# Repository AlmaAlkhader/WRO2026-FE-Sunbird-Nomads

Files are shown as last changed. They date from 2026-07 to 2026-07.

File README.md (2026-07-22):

<h1 align="center">Sunbird Nomads</h1>

<h3 align="center">
WRO 2026 Future Engineers · Palestine 🇵🇸
</h3>

<p align="center">
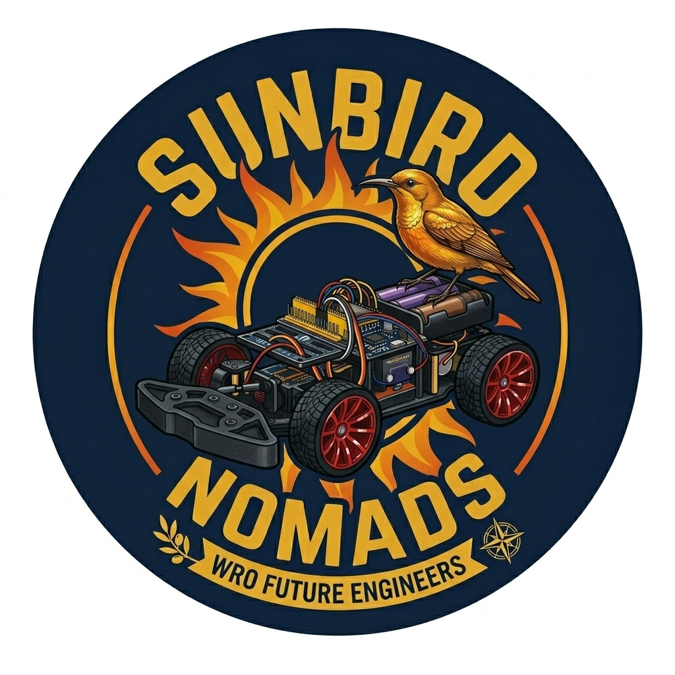
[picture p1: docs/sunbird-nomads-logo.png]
Sunbird Nomads team logo
  
</p>

<p align="center">
An autonomous vehicle engineered through testing, failure, redesign, and continuous improvement.
</p>

---

##  Repository Contents

| Folder | Contents |
|---|---|
| [`t-photos/`](t-photos/) | Official and informal team photos |
| [`v-photos/`](v-photos/) | Vehicle photographs from every required angle |
| [`video/`](video/) | Driving demonstration videos |
| [`schemes/`](schemes/) | Electrical and wiring diagrams |
| [`src/`](src/) | Testing and final robot software |
| [`models/`](models/) | 3D-printing and CAD files |
| [`docs/`](docs/) | Engineering diagrams and detailed investigations |

---
##  Why “Sunbird Nomads”?

<p align="center">
  Visual explanation of the Sunbird Nomads team name
</p>

The **Palestine sunbird** is a small, colourful bird native to our region and recognized as the national bird of Palestine. For Palestinians, it represents our land, identity, freedom, and resilience.

The word **Nomads** reflects our engineering journey constantly exploring, adapting, learning, and moving toward better solutions.

Together, **Sunbird Nomads** represents a Palestinian team deeply rooted in its homeland while continuing to move forward and discover new possibilities.

---
## Our Journey

We are **Alma Alkhader** and **Sara Afifi**, two second-year engineering students at Birzeit University brought together by a shared interest in robotics. This is our second year competing in the WRO Future Engineers category. Our experience began with our [WRO 2025 BiruniVerse project](https://github.com/AlmaAlkhader/WRO2025-BiruniVerse), where we gained our first practical experience designing, building, and programming an autonomous vehicle.

###  Meet the Team

<table>
  <tr>
    <th width="50%">Alma Alkhader</th>
    <th width="50%">Sara Afifi</th>
  </tr>
  <tr>
    <td align="center">
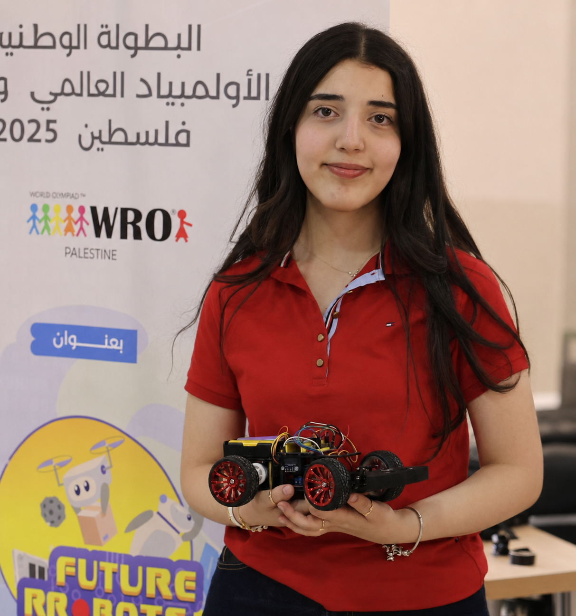
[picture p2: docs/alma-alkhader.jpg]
Alma Alkhader
      
    </td>
    <td align="center">
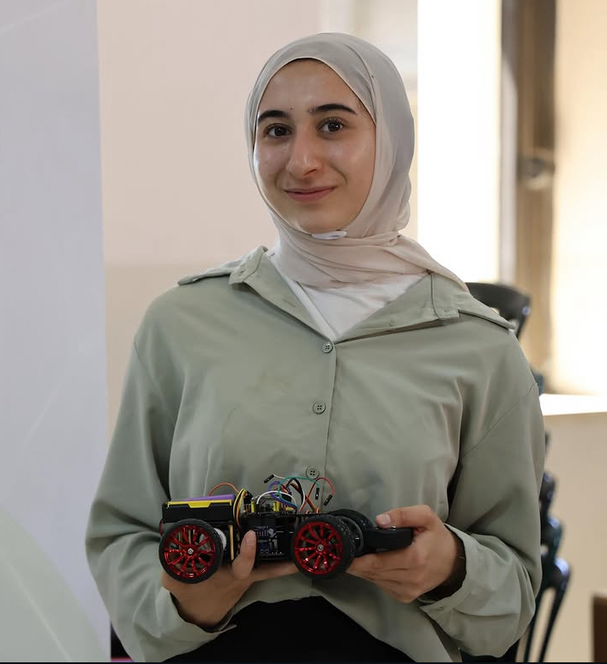
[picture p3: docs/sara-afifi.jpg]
Sara Afifi
      
    </td>
  </tr>
  <tr>
    <td valign="top">
      <strong>Occupation:</strong> Computer Engineering student<br><br>
      <strong>Academic level:</strong> Second year<br><br>
      <strong>Membership:</strong> IEEE Robotics and Automation Society (RAS), Birzeit University Student Branch<br><br>
      <strong>Interest:</strong> Robotics and autonomous systems<br><br>
      <strong>Team responsibilities:</strong> Power system, electronics, wiring, sensor integration, Raspberry Pi setup, and control software
    </td>
    <td valign="top">
      <strong>Occupation:</strong> Mechanical Engineering student<br><br>
      <strong>Academic level:</strong> Second year<br><br>
      <strong>Membership:</strong> Technical member of IMechE at Birzeit University<br><br>
      <strong>Specialization:</strong> Mechanical design and manufacturing<br><br>
      <strong>Team responsibilities:</strong> Chassis development, steering mechanism, component placement, measurements, and custom-designed mounts
    </td>
  </tr>
</table>

Our different specializations allowed us to approach the robot from two connected perspectives. Alma concentrated on making the electronics and software work reliably, while Sara focused on ensuring that the mechanical design could support those systems and move effectively. Nearly every improvement required both sides to work together.

<p align="center">
  Alma's electronics path and Sara's mechanical-design path joining into one robot engineering journey
  <br>
  <em>Two specializations developed together through every prototype, redesign, and milestone.</em>
</p>

Our first robot of the 2026 season came to life on **May 19, 2026**, powered by an ESP32. Although it completed the Open Challenge, it still faced major issues with steering, power delivery, and the rear axle. Over the following weeks, we redesigned and improved these systems while balancing the project with our university exams and coursework.

By the local competition on **July 13, 2026**, the robot had evolved significantly. After moving from the ESP32 to a Raspberry Pi and making several mechanical and electrical improvements, it achieved the maximum score in the Open Challenge. We earned **second place** and qualified for the national competition.

We are proud of how far the robot has come. Every test, mistake, and redesign contributed to the final architecture documented in this repository.

## Design Strategy

Our robot is built on a **4WD Arduino RC car chassis**, which we chose as a reliable starting point that allowed us to focus on developing and improving the robot for the WRO Future Engineers competition.

While the kit provided a solid foundation, it also presented several challenges:

* **Limited space** for mounting electronic components, requiring us to carefully redesign the layout and create custom 3D-printed mounts.
* **Minimal assembly documentation**, which led us to reverse-engineer parts of the chassis and solve several mechanical issues during development.

As the project evolved, we continuously modified the original design to better meet the competition's requirements, improving the mechanical structure, electronics integration, and overall reliability.

# Hardware Design
## Mobility and Mechanical Design

The mechanical system uses a conventional car layout: a **single rear drive axle** provides forward and reverse motion, while an **S3003 servo** steers the two front wheels through linkages. This layout satisfies the WRO requirement for a four-wheeled vehicle with one driving axle and one steering actuator, and it behaves more like a road car than a differential-drive robot.

### Chassis and Drive Layout

Our robot is based on the [**RoboticX 4WD RC Smart Car Chassis with S3003 Servo and Bearing Kit**](https://roboticx.ps/product/4wd-rc-smart-car-chassis-with-s3003-metal-servo-bearing-kit-for-arduino/). 
We selected the kit as a reliable mechanical starting point, but we did not keep its original component layout. Its acrylic plate had limited usable space and mounting holes intended mainly for an Arduino. Our Raspberry Pi, power system, camera, motor controller, and sensors required a new structure, so we designed a custom middle plate and an upper electronics layer.

<p align="center">
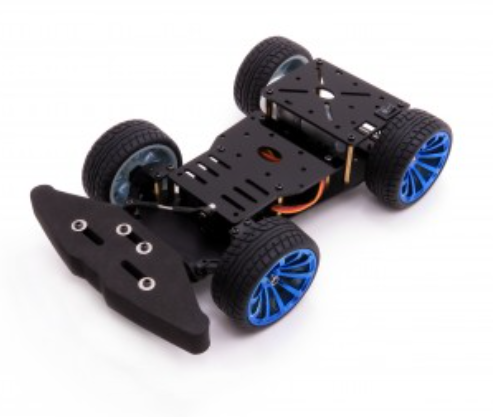
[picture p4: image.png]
Original RoboticX rear-wheel-drive chassis
  
  <br>
  <em>Original chassis before adding the custom two-level electronics structure.</em>
</p>

### Final Vehicle Dimensions

| Dimension | Final value | How it was obtained | Why it matters |
|---|---:|---|---|
| Overall length | 248 mm | Measured vehicle length; also matches the chassis listing | Determines WRO envelope margin and parking-space length |
| Chassis width | 146 mm | Published chassis width | Determines lateral clearance and field-centering geometry |
| Assembled height | 126 mm | Measured with the upper electronics layer installed | Confirms that the two-level design remains inside the height limit |
| Wheelbase | 137 mm | Measured axle-to-axle distance | Used in steering-angle calculations |
| Front track width | 117 mm | Measured between the front wheel centerlines | Used to calculate different inner and outer steering angles |
| Wheel diameter | 64 mm | Published wheel diameter | Determines distance travelled per wheel revolution |
| Ground clearance | 19 mm | Measured from the ground to the lowest chassis surface | Reduces the chance of the plate catching on small field irregularities |

<p align="center">
  Top and side views with the robot's mechanical dimensions and field-fit calculations
  <br>
  <em>Final dimensions, WRO size margins, wheel travel, and parking-space calculations.</em>
</p>

The [WRO 2026 rules](https://wro-association.org/wp-content/uploads/WRO-2026-Future-Engineers-Self-Driving-Cars-General-Rules.pdf) limit the vehicle to **300 × 200 mm** and **300 mm in height**. Comparing the final robot with that envelope gives:

```text
Length margin = 300 − 248 = 52 mm
Width margin  = 200 − 146 = 54 mm
Height margin = 300 − 126 = 174 mm
```

These are total envelope margins. They show that the second electronics layer and sensor mounts remain within the dimensional limit without requiring parts to be removed before inspection.

### Field-Centering and Parking Geometry

During setup, we established the robot's centerline by measuring from the track walls to the midpoint of the vehicle. For a corridor width $W_t$, a centered robot midpoint is:

$$d_{mid}=\frac{W_t}{2}$$

The open challenge may use a **1000 mm** or **600 mm** corridor, while the obstacle challenge uses a **1000 mm** corridor. The nominal midpoint references are therefore:

| Nominal corridor width | Wall-to-midpoint reference | Side clearance with a 146 mm robot |
|---:|---:|---:|
| 1000 mm | 500 mm | $(1000-146)/2=427$ mm per side |
| 600 mm | 300 mm | $(600-146)/2=227$ mm per side |

The WRO rules allow dimensional tolerance in the field, so these values define the geometry rather than a single inflexible sensor threshold.

For the obstacle challenge, the parking space is **200 mm wide**, and its length is $1.5$ times the vehicle length:

```text
Parking length = 1.5 × 248 = 372 mm
Longitudinal allowance = 372 − 248 = 124 mm
Lateral allowance = 200 − 146 = 54 mm
Centered lateral allowance = 54 / 2 = 27 mm per side
```

The remaining **VL53L0X ToF sensor is mounted at the rear** and is used to monitor the final rear clearance during parking. Its job is separate from the left and right ultrasonic sensors used for wall sensing.

### Custom Plate Development

After identifying the required components, we designed custom middle and top plates to increase usable mounting area while preserving access to wiring and controls. The plate design went through **four physical iterations**. Our initial measurements were not accurate enough to produce a correct fit on the first attempt, so every printed version was installed on the real chassis, checked, remeasured, and revised.

<table align="center">
  <tr>
    <td align="center">
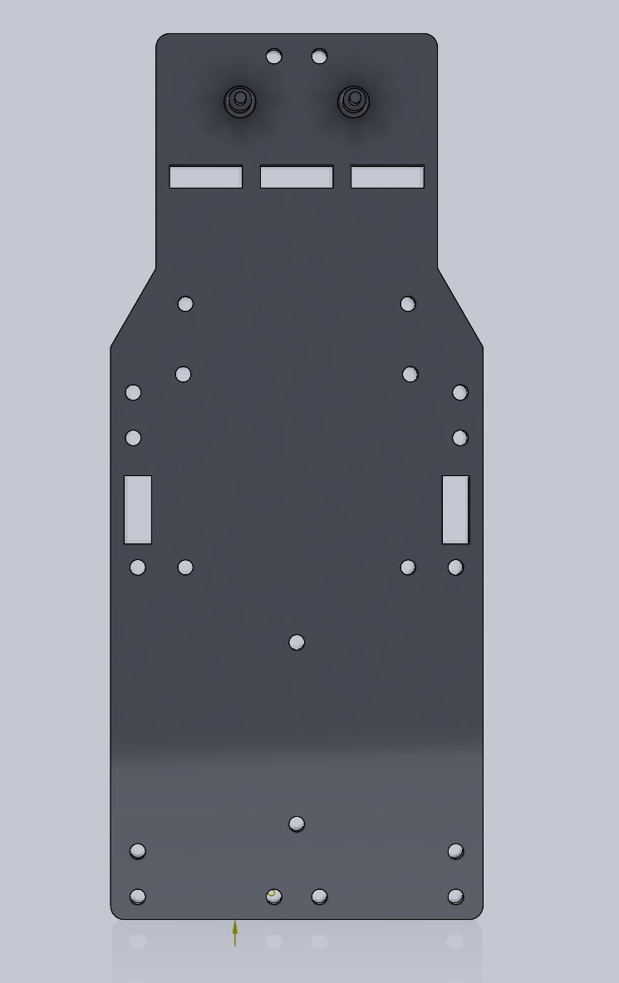
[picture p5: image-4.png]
middle plate
      <br>
      <em>Early prototype</em>
    </td>
    <td align="center">
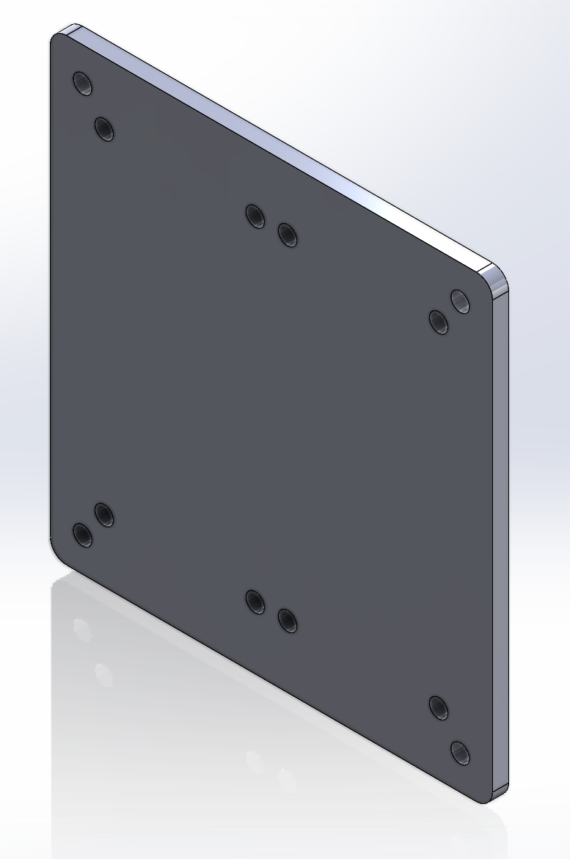
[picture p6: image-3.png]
top plate
      <br>
      <em>Final design</em>
    </td>
  </tr>
</table>

<p align="center">
  Measure, model, print, fit-test, and refine loop used across four plate versions
  <br>
  <em>The physical fit test converted measurement errors into specific CAD corrections.</em>
</p>

The process was not simply “print until it looks right.” Each loop checked whether components fitted without interference, whether cables could reach without being sharply bent, whether switches remained accessible, and whether the camera and sensors had an unobstructed view. Repeating the cycle improved component placement, cable management, and service access.

### 3D-Printing Configuration

The final plates were produced by FDM printing on an **ELEGOO Centauri Carbon** using **Rapid PETG**. ELEGOO lists PETG as a supported material and specifies a **0.1–0.4 mm** layer-height range for this printer; our **0.12 mm** setting is near the fine-detail end of that range.

| Setting | Final value | Engineering purpose |
|---|---:|---|
| Printer | ELEGOO Centauri Carbon | Enclosed CoreXY FDM printer used for the final plates |
| Material | Rapid PETG | Tougher functional material for plates handled and reassembled repeatedly |
| Layer height | 0.12 mm | Finer vertical resolution and more controlled fit, at the cost of longer print time |
| Wall loops | 3 | Adds perimeter stiffness around the plate edges and mounting holes |
| Sparse infill pattern | Gyroid | Distributes internal support in multiple directions without using solid infill everywhere |
| Sparse infill density | 25% | Balances rigidity, material use, mass, and print time |

Compared with the printer's commonly recommended **0.20 mm** layer height, a 0.12 mm layer produces approximately:

$$\frac{0.20}{0.12}=1.67$$

or **67% more layers for the same part height**. We accepted the longer printing time because dimensional fit and clean mount features were more important than minimum production time for the final plates.

Printer reference: [ELEGOO Centauri Carbon specifications](https://eu.elegoo.com/en-be/products/centauri-carbon).

## Steering Calibration

The chassis allows the steering-rod lengths to be adjusted. We used this to approximate **Ackermann steering**, where the inner front wheel turns more sharply than the outer front wheel because the two wheels follow different radii around the same instantaneous center of rotation.

<p align="center">
  Animated Ackermann steering geometry showing inner and outer wheel angles and the instantaneous center of rotation
  <br>
  <em>Animated steering geometry for an illustrative 200 mm turn radius. The 44° inner and 28° outer angles are calculated from our measured wheelbase and front track.</em>
</p>

<p align="center">
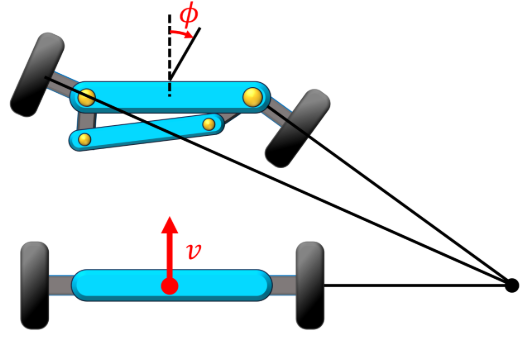
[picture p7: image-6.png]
Ackermann steering mechanism
  
</p>

For low-speed cornering, the centerline steering angle is:

$$\delta=\tan^{-1}\left(\frac{L}{R}\right)$$

Using the measured wheelbase $L=137$ mm and turning radius $R=525$ mm:

$$\delta=\tan^{-1}\left(\frac{137}{525}\right)=14.6^\circ\approx15^\circ$$

The measured front track width $t=117$ mm lets us estimate the ideal inner and outer wheel angles:

$$\delta_{in}=\tan^{-1}\left(\frac{L}{R-t/2}\right)
=\tan^{-1}\left(\frac{137}{525-58.5}\right)=16.4^\circ$$

$$\delta_{out}=\tan^{-1}\left(\frac{L}{R+t/2}\right)
=\tan^{-1}\left(\frac{137}{525+58.5}\right)=13.2^\circ$$

| Steering reference | Calculated angle |
|---|---:|
| Vehicle centerline | 14.6° |
| Inner front wheel | 16.4° |
| Outer front wheel | 13.2° |
| Inner-to-outer difference | 3.2° |

We adjusted the steering rods until the wheels followed this geometry as closely as the kit mechanism allowed. This reduces tire scrub compared with forcing both front wheels to the same angle.

## Mounts

The camera and distance sensors use custom-designed mounts so their position does not change during a run while remaining accessible for maintenance.

### ToF Sensor Mount — Initial Design and Final Rear Use

Our first approach used multiple Time-of-Flight sensors for wall sensing. After several design iterations, we produced a stable ToF mount.

<p align="center">
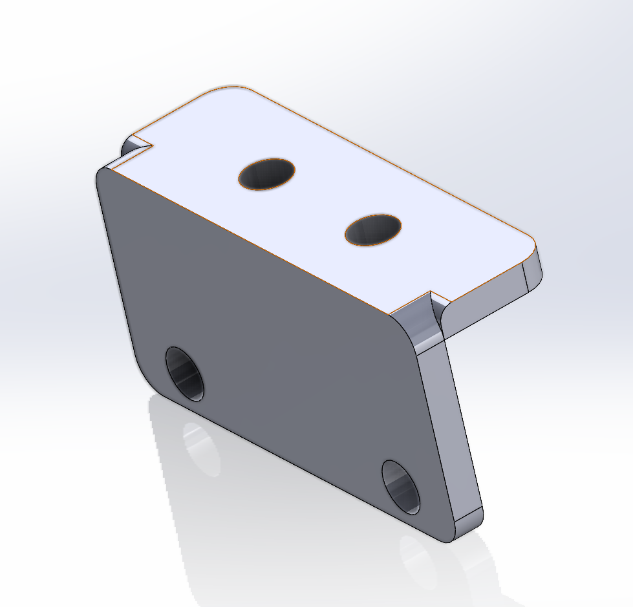
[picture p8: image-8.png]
ToF sensor mount design
  
  <br>
  <em>ToF sensor mount design.</em>
</p>

Testing showed that ToF sensors were not suitable as our main wall sensors on the WRO mat because infrared return varied with dark surfaces and target geometry. We replaced the side-facing ToF plan with ultrasonic wall sensing. **One VL53L0X remains mounted on the back of the vehicle for short-range parking alignment.**

### Ultrasonic Sensor Mount — Final Design

The left and right ultrasonic sensors required a different mount that kept both transducers clear of the chassis.

<p align="center">
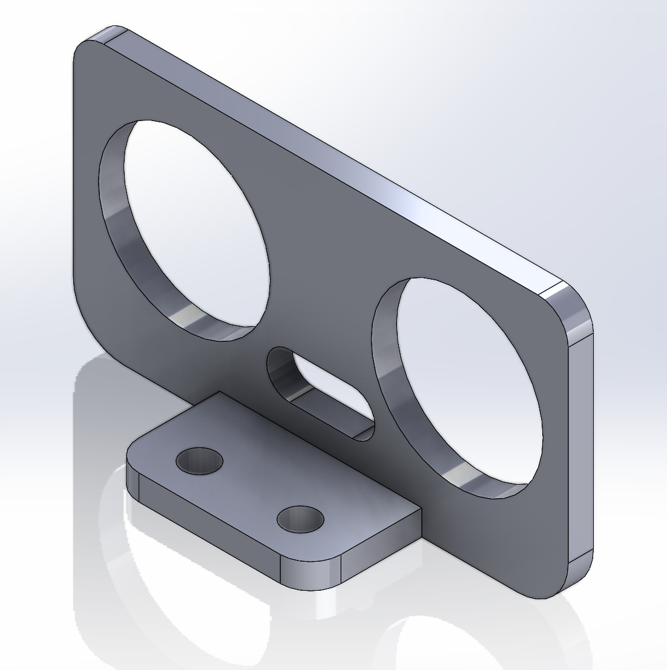
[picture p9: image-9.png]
Ultrasonic sensor mount design
  
  <br>
  <em>Final ultrasonic sensor mount design.</em>
</p>

The mount uses a **friction-fit mechanism** to hold the sensor without screws. This makes installation and replacement fast, but it also made print accuracy important: an undersized opening could damage the board, while an oversized opening allowed the sensor angle to change.

### Pi Camera Mount

The camera requires a stable, repeatable position because a change in height or angle changes the apparent location of the traffic pillars. We designed a screw-mounted holder with an unobstructed lens opening.

<p align="center">
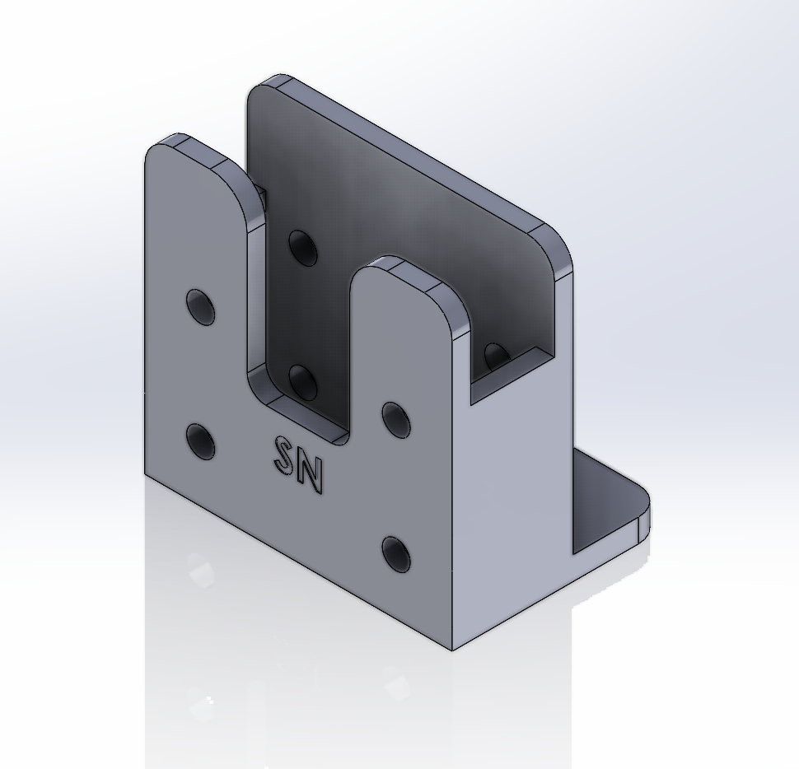
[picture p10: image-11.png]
Pi Camera mount design
  
  <br>
  <em>Custom camera mount on the second level at the front of the robot.</em>
</p>

The camera is installed vertically on the second level, facing forward with its optical axis approximately parallel to the field. The **“SN”** engraving identifies the mount as a Sunbird Nomads part.

# Power & Sensor Architecture

Our electrical design separates the noisy, high-current drive system from the Raspberry Pi's processing supply. A three-cell motor battery powers the H-bridge, drive motor, and steering-servo rail, while a dedicated USB power bank powers the Raspberry Pi 4 and camera. The two sources share a common ground so that the Raspberry Pi's control signals have the same electrical reference as the H-bridge and servo.

This section uses the robot's confirmed configuration, values recovered from our project records, and manufacturer specifications. No unrecorded measurement is presented as a test result.

## Main Electrical Components

<table align="center">
  <tr>
    <td align="center" width="33%">
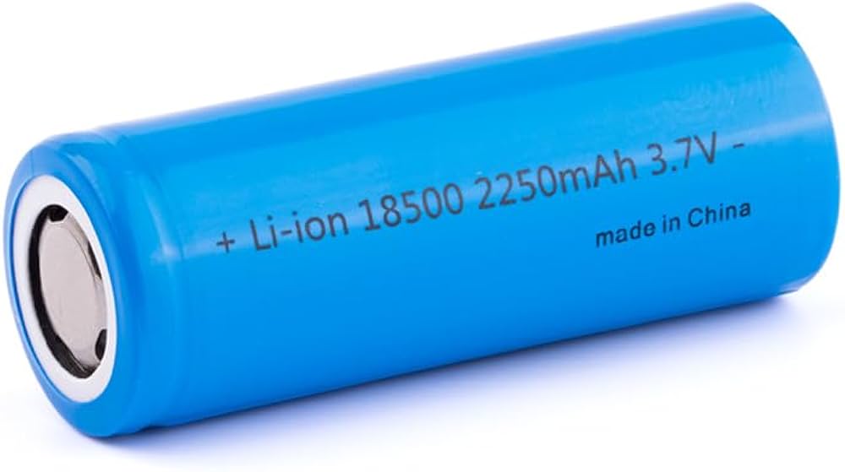
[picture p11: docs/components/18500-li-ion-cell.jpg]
18500 lithium-ion battery cell
      <br>
      <strong>3 × 18500 Li-ion cells</strong><br>
      <sub>3.7 V, 2250 mAh per cell</sub>
    </td>
    <td align="center" width="33%">
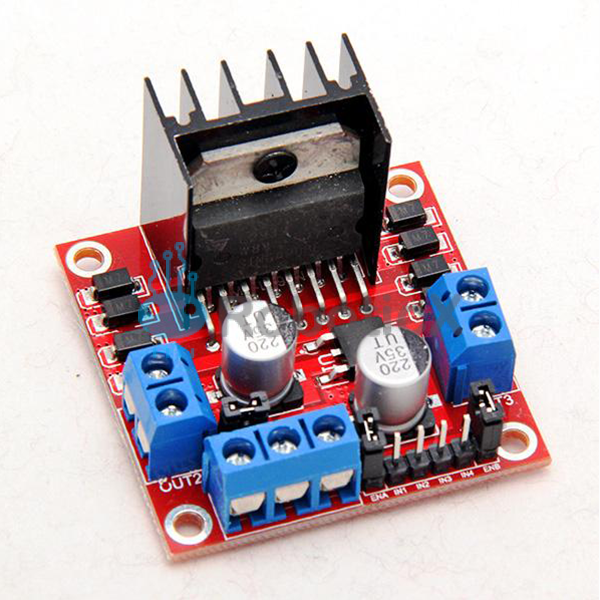
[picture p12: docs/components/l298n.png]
L298N motor-controller module
      <br>
      <strong>L298N motor controller</strong><br>
      <sub>Purchased separately from the chassis</sub>
    </td>
    <td align="center" width="33%">
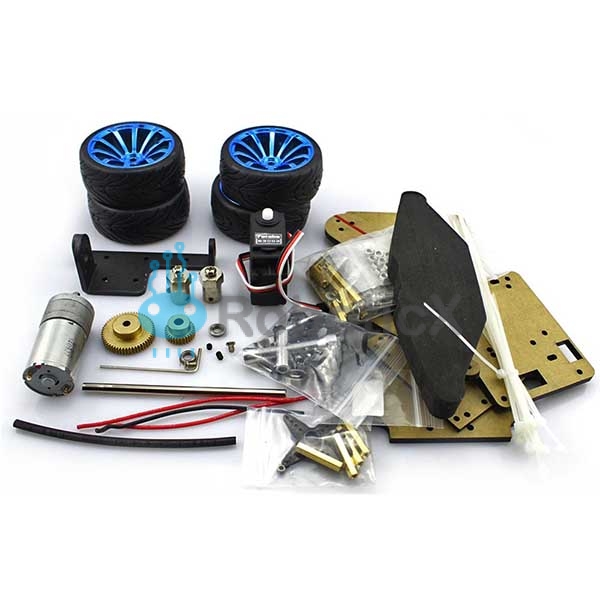
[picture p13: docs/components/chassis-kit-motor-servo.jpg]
Chassis kit containing S3003 servo and 25 millimetre gearmotor
      <br>
      <strong>S3003 servo + 25 mm gearmotor</strong><br>
      <sub>Supplied with the RoboticX chassis</sub>
    </td>
  </tr>
</table>

<p align="center">
  <sub>Component sources: team battery record and the RoboticX <a href="https://roboticx.ps/product/dual-motor-controller-module-l298n/">L298N</a> and <a href="https://roboticx.ps/product/4wd-rc-smart-car-chassis-with-s3003-metal-servo-bearing-kit-for-arduino/">chassis-kit</a> listings.</sub>
</p>

## System Architecture

<p align="center">
  Power and control distribution diagram
  <br>
  <em>Confirmed power paths, connected loads, control signals, and shared ground.</em>
</p>

The power switch energizes the drive system. A separate start control launches the autonomous program, allowing the robot to be powered and checked before motion begins.

## Power Sources and Distribution

| Source or rail | Connected loads | Confirmed information |
|---|---|---|
| 3S motor pack | L298N H-bridge, drive motor, servo rail | 3 × 18500 Li-ion cells, each labelled 3.7 V and 2250 mAh |
| USB power bank | Raspberry Pi 4, camera, and Pi-side sensors | Billboard 10,000 mAh, 5 V / 3 A output |
| L298N motor output | 25 mm all-metal gearmotor | PWM speed and direction control |
| H-bridge module 5 V terminal | S3003 steering servo | Servo power and ground; control signal from Raspberry Pi GPIO12 |
| Raspberry Pi 3.3 V and GPIO | Ultrasonic and ToF sensor logic | Common ground through the breadboard negative rail |

<p align="center">
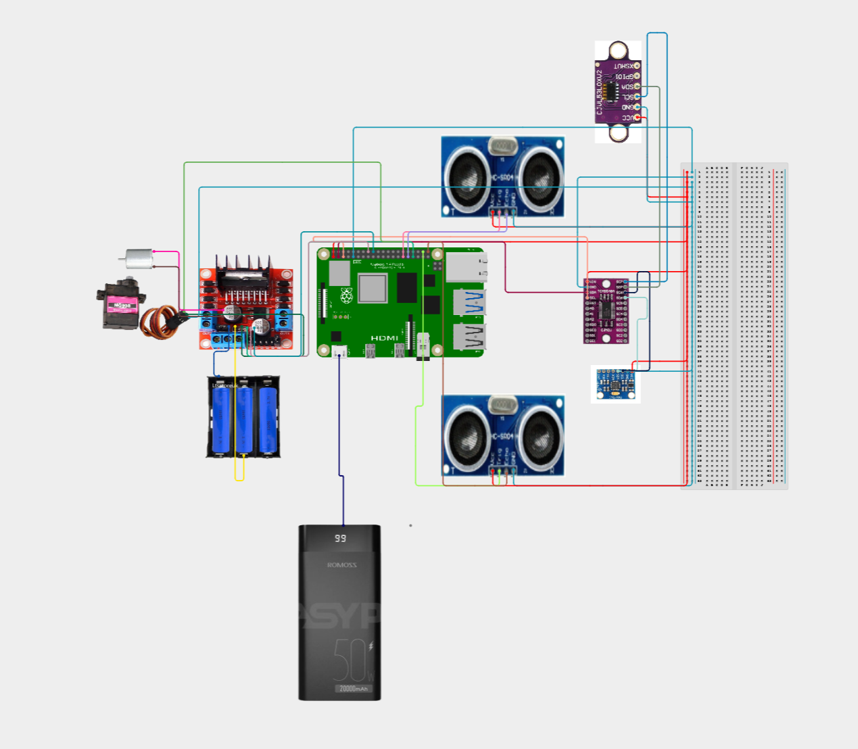
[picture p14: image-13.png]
A wiring diagram of the autonomous vehicle
  
</p>

The Raspberry Pi 4 requires a good-quality **5 V, 3 A** USB-C supply according to its [official datasheet](https://pip.raspberrypi.com/documents/RP-008341-DS-raspberry-pi-4-datasheet.pdf). The power bank's labelled output matches that supply requirement.

### 3S Motor-Battery Calculation

The cells are connected in series. Series connection adds voltage, but it does **not** add ampere-hour capacity:

```text
Nominal pack voltage = 3 × 3.7 V = 11.1 V
Fully charged voltage = 3 × 4.2 V = 12.6 V
Pack capacity = 2.25 Ah
Nominal stored energy = 11.1 V × 2.25 Ah = 24.975 Wh ≈ 25.0 Wh
```

The 3S pack therefore supplies approximately **12.6 V when fully charged** and **11.1 V at nominal charge**. The voltage reaching the motor is lower because the L298N has an internal voltage drop.

### H-Bridge Trade-off and Voltage Loss

The installed driver is the separately purchased [**RoboticX L298N dual motor-controller module**](https://roboticx.ps/product/dual-motor-controller-module-l298n/). Its seller specifications list a **6–15 V motor-supply range**, **4.5–5.5 V logic range**, **2 A maximum drive current**, and **0–100% output duty cycle**.

The [STMicroelectronics L298 datasheet](https://www.st.com/resource/en/datasheet/l298.pdf) specifies a total bridge saturation-voltage drop of approximately **1.8 V typical and up to 3.2 V at 1 A**. At a nominal 11.1 V pack voltage:

```text
Motor voltage ≈ battery voltage − bridge drop
Best reference case: 11.1 V − 1.8 V = 9.3 V
High-drop case:      11.1 V − 3.2 V = 7.9 V
```

The corresponding driver heat at 1 A is approximately:

```text
Driver loss = current × voltage drop
             = 1 A × (1.8 to 3.2 V)
             = 1.8 to 3.2 W
```

This older bipolar driver is simple and readily available, but it sacrifices motor voltage and produces more heat than a modern MOSFET driver. We retained it because it was already integrated and provided the required PWM speed and direction control.

## Documented Electrical Load Data

| Load | Supply | Datasheet or seller value | Why it matters |
|---|---:|---|---|
| Raspberry Pi 4 system | 5 V | 3 A recommended supply capability | Establishes the required continuous output of the USB power bank and cable |
| Left HC-SR04-type sensor | Installed at 3.3 V | Standard HC-SR04 reference: 15 mA at 5 V | Distinguishes the installed working configuration from the standard module specification |
| Right HC-SR04-type sensor | Installed at 3.3 V | Standard HC-SR04 reference: 15 mA at 5 V | Uses the same supply and reference as the left sensor |
| Rear VL53L0X | Raspberry Pi sensor rail | Bare sensor: 19 mA typical active and up to 40 mA peak | Accounts for the parking sensor's load on the Pi-side rail |
| L298N motor controller | 3S motor pack | 6–15 V motor supply, 4.5–5.5 V logic, and 2 A maximum drive current | Confirms compatibility with the motor pack and defines the controller's published current limit |

Sources: [Raspberry Pi 4 datasheet](https://pip.raspberrypi.com/documents/RP-008341-DS-raspberry-pi-4-datasheet.pdf), [HC-SR04 reference sheet](https://cdn.sparkfun.com/datasheets/Sensors/Proximity/HCSR04.pdf), [STMicroelectronics VL53L0X datasheet](https://www.st.com/resource/en/datasheet/vl53l0x.pdf), and [RoboticX L298N product page](https://roboticx.ps/product/dual-motor-controller-module-l298n/).

The power sources are intentionally separated: the 3S pack handles drive and steering loads, while the USB power bank isolates the Raspberry Pi and vision system from motor-current transients.

## Signal and GPIO Map

| Device | Function | BCM GPIO | Physical pin | Interface |
|---|---|---:|---:|---|
| Left ultrasonic | Trigger | GPIO5 | 29 | Digital output |
| Left ultrasonic | Echo | GPIO6 | 31 | Digital input |
| Right ultrasonic | Trigger | GPIO20 | 38 | Digital output |
| Right ultrasonic | Echo | GPIO21 | 40 | Digital input |
| Rear VL53L0X | SDA | GPIO2 | 3 | I²C data |
| Rear VL53L0X | SCL | GPIO3 | 5 | I²C clock |
| Steering servo | PWM signal | GPIO12 | 32 | 50 Hz PWM |
| H-bridge enable | Motor speed | GPIO13 | 33 | 1 kHz PWM |
| H-bridge IN1 | Motor direction | GPIO23 | 16 | Digital output |
| H-bridge IN2 | Motor direction | GPIO24 | 18 | Digital output |

All grounds are joined on the breadboard negative rail. This common reference is necessary because the Pi sends control signals to devices powered from the motor-side supply.

## Sensor Roles, Selection, and Placement

| Sensor | Final role | Why it was selected | Main limitation |
|---|---|---|---|
| Left ultrasonic | Measure distance to the left wall and detect openings | Measures by reflected sound, so wall colour has much less influence than on optical ranging | Wide beam can reflect from angled surfaces; can cross-talk with another ultrasonic sensor |
| Right ultrasonic | Measure distance to the right wall and detect openings | Same device type on both sides simplifies comparison and replacement | Requires timing separation and has a 2 cm reference blind zone |
| Rear VL53L0X ToF | Short-range parking alignment | Narrower optical field of view is useful for alignment with the rear parking boundary | Infrared return can depend on target reflectance, angle, and cover-glass crosstalk |
| Arducam 12 MP IMX708 | Detect red and green traffic pillars | High-resolution colour frames support HSV segmentation and pillar-position estimation | Processing full-resolution frames increases latency; fixed focus reduces near-field sharpness |

### Distance-Sensor Reference Photos

<table align="center">
  <tr>
    <td align="center" width="50%">
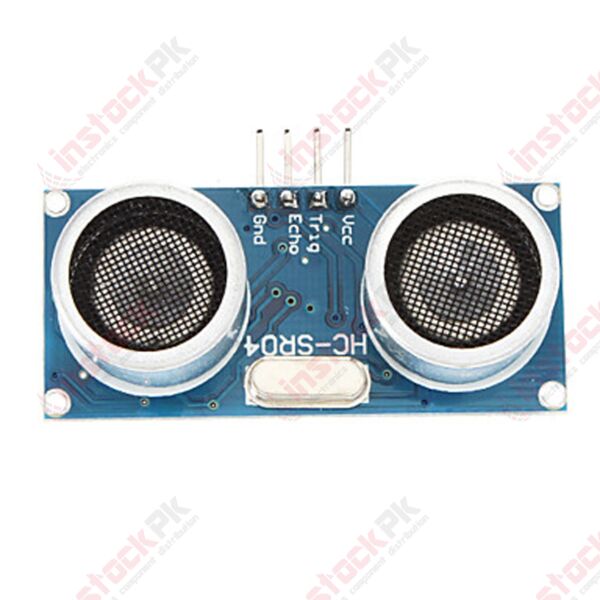
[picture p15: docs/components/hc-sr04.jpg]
HC-SR04 ultrasonic distance sensor
      <br>
      <strong>2 × HC-SR04-type ultrasonic sensors</strong><br>
      <sub>Left and right wall sensing</sub>
    </td>
    <td align="center" width="50%">
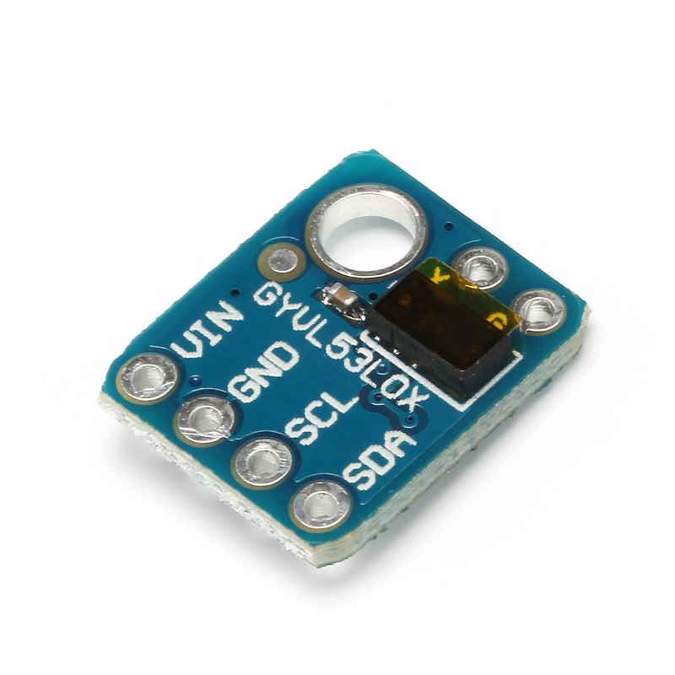
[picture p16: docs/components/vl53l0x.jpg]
VL53L0X time-of-flight sensor module
      <br>
      <strong>1 × VL53L0X ToF sensor</strong><br>
      <sub>Rear parking-distance sensing</sub>
    </td>
  </tr>
</table>

<p align="center">
  <sub>Reference images: <a href="https://instock.pk/hc-sr04-ultrasonic-sensor-distance-measuring-module.html">HC-SR04</a> and <a href="https://store.fut-electronics.com/products/vl53l0x-time-of-flight-sensor-precision-distance-measurements">VL53L0X module</a>.</sub>
</p>

The ultrasonic sensors face left and right so that each one has a direct line of sight to one track wall. This placement supports wall-distance comparison and exposes the sudden open-space reading used to identify corners. The rear-facing ToF sensor is separated from this navigation pair because its role is parking clearance rather than turn detection.

<p align="center">
  Conceptual top view of the robot sensor layout
  <br>
  <em>Conceptual top view showing each sensor's direction and role; component positions are not dimensioned.</em>
</p>

The rear ToF sensor is used specifically for **parking**, not front obstacle detection. It measures the remaining rear clearance during the final parking maneuver.

### Placement Constraints from Field Geometry

The [WRO 2026 Future Engineers rules](https://wro-association.org/wp-content/uploads/WRO-2026-Future-Engineers-Self-Driving-Cars-General-Rules.pdf) define physical targets that directly affect sensor placement:

| Field feature | Rule dimension | Design consequence |
|---|---:|---|
| Interior and exterior walls | 100 mm high | The ultrasonic acoustic center should remain below the wall top and clear of wheels/mounts |
| Traffic pillars | 50 × 50 × 100 mm | Camera resolution must preserve a useful contour for a 50 mm-wide target at the required detection distance |
| Parking boundary elements | 200 × 20 × 100 mm | Rear ToF line of sight must intersect the 100 mm-high element during parking |
| Maximum vehicle envelope | 300 × 200 × 300 mm | Camera and sensor mounts must remain inside the permitted footprint and height |
| Obstacle Challenge track width | 1000 ± 10 mm | Side ranges must cover the relevant wall distance while leaving margin for turns and openings |

The HC-SR04 reference datasheet lists a **15° measuring angle**. Approximating this as a conical beam, its footprint width at target distance $d$ is:

$$W_{US}=2d\tan(15^\circ/2)$$

| Target distance | Approximate ultrasonic footprint width |
|---:|---:|
| 20 cm | 5.3 cm |
| 50 cm | 13.2 cm |
| 100 cm | 26.3 cm |

Ultrasonic sensors detect objects across a wide area, so they may sometimes pick up nearby wheels, mounts, corners, or angled walls instead of the intended wall. The rear VL53L0X sensor observes a smaller area, making it more suitable for precise parking-distance measurements.

### Ultrasonic Timing and Crosstalk Control

The standard HC-SR04 datasheet recommends a measurement cycle longer than **60 ms**. Our code does not trigger both sensors together: it reads the left sensor, waits **60 ms**, then reads the right sensor. Sequential triggering reduces the chance that one receiver mistakes the other sensor's sound burst for its own echo.

The control loop also applies a three-sample median filter. A median rejects one isolated high or low reading without being shifted as strongly as a mean:

```text
Filtered distance = median(last three valid readings)
```

This filtering and delay improve robustness at the cost of a slower sensing update. The dashboard therefore prioritizes stable wall readings over maximum update rate.

### HC-SR04 Voltage Configuration

The installed ultrasonic sensors operate when powered from **3.3 V**, and no Echo voltage divider is used. This is the robot's observed configuration. The commonly published HC-SR04 reference sheet instead specifies **5 V operation**, while Raspberry Pi GPIO uses a **3.3 V I/O rail**. For that reason, this repository does not generalize the robot's observed 3.3 V behaviour to every HC-SR04 board revision.

## Camera Hardware and Colour Pipeline

The installed camera is an **Arducam 12 MP IMX708 fixed-focus HDR camera**. Arducam specifies a maximum sensor resolution of **4608 × 2592**, a 1.4 µm pixel size, and a fixed-focus range listed as 1.5 m to infinity for this module family in its [IMX708 documentation](https://docs.arducam.com/Raspberry-Pi-Camera/Native-camera/12MP-IMX708/). The camera is used for colour detection rather than full-resolution recording.

The existing colour-detection program uses **Picamera2** for capture and **OpenCV** for BGR-to-HSV conversion and contour detection. The currently recorded code values are:

| Parameter | Current code value |
|---|---|
| Green HSV lower bound | `[115, 200, 100]` |
| Green HSV upper bound | `[160, 255, 180]` |
| Red HSV lower bound | `[0, 80, 60]` |
| Red HSV upper bound | `[30, 255, 255]` |
| Minimum contour area | `800 px²` |
| Loop delay | `0.05 s` |

Picamera2 is the Python interface to Raspberry Pi's `libcamera`-based camera stack, as described in the [official Raspberry Pi camera documentation](https://www.raspberrypi.com/documentation/computers/camera_software.html). The new camera is producing colour detections with the recorded OpenCV pipeline.

## Recorded Integration Observations

These are the exact values retained from earlier individual hardware checks. They confirm communication, but the true target distances were not recorded, so they cannot be used to claim accuracy.

| Device | Recorded observation | What it proves | What it does not prove |
|---|---:|---|---|
| VL53L0X | 159 mm, followed by changing readings | I²C initialization and live ranging worked | Accuracy, parking repeatability, or surface independence |
| Left ultrasonic | Approximately 47–49 cm | Trigger/Echo path returned plausible changing data | Error at a known distance or invalid-reading rate |
| Right ultrasonic | 8.9 cm | Individual sensor read worked at short range | Cross-sensor consistency or calibrated accuracy |

## Failure-Point Analysis

| Failure mode | Effect on robot | Current design response |
|---|---|---|
| Two ultrasonic bursts overlap | False wall distance and incorrect turn decision | Sensors are triggered sequentially with 60 ms separation and a median-of-three filter |
| L298N voltage drop | Reduced motor voltage and power lost as heat | The loss is calculated above and the robot uses conservative PWM settings |
| Motor electrical noise reaches processing electronics | Sensor errors or controller reset | The Raspberry Pi and camera use a separate USB power bank while all control signals retain a common ground reference |
| Camera colour shifts | Missed or incorrect pillar classification | HSV bounds are combined with an 800 px² contour-area threshold |
| Ultrasonic VCC/GND reversed | Sensor heating and possible damage | The earlier incident was stopped immediately; common-rail wiring and pin checks were adopted afterward |
| Unprotected 3S cell pack is overcharged, over-discharged, imbalanced, or shorted | Cell damage, heating, fire risk, or sudden shutdown | The pack has a physical isolation switch, but no BMS or fuse is installed |

The switch is useful for isolation, but it is **not** a substitute for a battery-management/protection circuit or fuse. The absence of a BMS and overcurrent protection is the highest-priority electrical risk in the current design.

## 🚀 Software Architecture & Obstacle Strategy

The uploaded Raspberry Pi program is a **testing and calibration controller for the Open Challenge**. It combines wall-distance sensing, a deterministic drive state machine, actuator control, live telemetry, and emergency-stop supervision in one inspectable system.

<p align="center">
  Sensor-to-actuator architecture of the Raspberry Pi testing controller
  <br>
  <em>Control flow in the uploaded testing controller. The rear ToF is displayed as telemetry; it does not influence the current turn decision.</em>
</p>

### Software Evidence in This Repository

| File | Responsibility |
|---|---|
| [`src/testing/dashboard.py`](src/testing/dashboard.py) | GPIO setup, sensor acquisition, filtering, turn decisions, state machine, motor/servo commands, watchdog, and HTTP API |
| [`src/testing/dashboard.html`](src/testing/dashboard.html) | Live sensor/state display and calibration controls |
| [`src/testing/README.md`](src/testing/README.md) | Wiring, installation, launch procedure, safety notes, and known limitations |

The repository does **not** currently contain a `src/final/` competition controller or the camera-based red/green pillar-avoidance program. The obstacle hardware is documented above, but this section does not claim obstacle behavior that cannot be reproduced from the uploaded source.

### Dashboard and Competition-Control Visuals

The dashboard image is evidence from the uploaded calibration interface. The remaining diagrams document the **agreed competition control specification**: rear-ToF task selection at 150 mm, camera priority during Task 2, red/green avoidance, and stopping after twelve completed corners. They do not claim an autonomous final-parking routine.

<table align="center">
  <tr>
    <td align="center" width="45%">
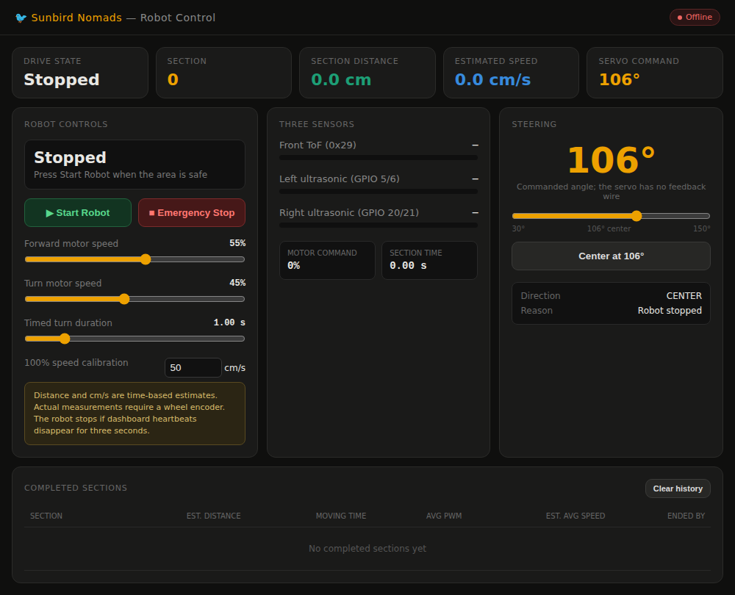
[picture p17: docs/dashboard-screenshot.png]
Sunbird live calibration dashboard
      <br>
      <strong>Calibration dashboard</strong><br>
      <sub>Live telemetry, steering, speed, timing, and safety controls</sub>
    </td>
    <td align="center" width="55%">
      Competition challenge selection and control strategy<br>
      <strong>Competition control specification</strong><br>
      <sub>Task selection, behavior priority, corner counting, and stop condition</sub>
    </td>
  </tr>
</table>

#### Camera Processing and ROI

<p align="center">
  Picamera2 and OpenCV obstacle detection pipeline
  <br>
  <em>Frame processing from ROI crop through HSV masks, contour filtering, colour selection, and steering.</em>
</p>

<p align="center">
  Conceptual camera ROI and closest-pillar selection
  <br>
  <em>The ROI removes irrelevant image regions. If both colours appear, the largest accepted contour is treated as the closest obstacle.</em>
</p>

#### Red and Green Avoidance Geometry

<p align="center">
  Top-down red and green pillar avoidance paths
  <br>
  <em>Red is passed on the right; green is passed on the left. Avoidance ends after the selected pillar is absent from the ROI for three consecutive frames.</em>
</p>

#### Corner and Lap Counting

<p align="center">
  Twelve-corner counter representing three completed laps
  <br>
  <em>One completed corner maneuver increments the counter. Four corners form one lap, and the robot stops after corner twelve.</em>
</p>

### Control Flow

The robot uses explicit states instead of mixing sensing, steering, and motor commands in one loop:

```mermaid
flowchart LR
    stopped -->|Start| forward
    forward -->|3 matching decisions after 1.5 s| turn_steer
    turn_steer -->|Servo settled: 0.45 s| turn_drive
    turn_drive -->|Timed turn complete| turn_recenter
    turn_recenter -->|Servo settled: 0.45 s| forward
    forward -->|Stop, emergency, or watchdog| stopped
```

| Current state | Exit condition | Action before next state |
|---|---|---|
| `stopped` | Start command | Center steering, begin a new section, drive forward |
| `forward` | Same turn candidate confirmed 3 times after the 1.5 s lockout | Stop motor and command the calibrated turn angle |
| `turn_steer` | 0.45 s settling time expires | Drive forward at the turn-speed setting |
| `turn_drive` | Configured turn duration expires | Stop motor and command center steering |
| `turn_recenter` | 0.45 s settling time expires | Begin the next forward section |
| Any active state | Stop, emergency stop, or heartbeat older than 3 s | Stop motor and recenter steering |

Stopping the drive motor before changing steering reduces the chance of a wheel catching a nearby mount. The trade-off is time: with the default 1.0 s turn, a complete turn sequence includes approximately **0.9 s of stationary servo-settling time** in addition to the driven turn.

### Sensor Acquisition and Noise Rejection

Each HC-SR04-type reading follows the same guarded sequence:

1. Reject an Echo pin that is already stuck HIGH.
2. Send a **10 µs** Trigger pulse.
3. Apply a **30 ms** timeout while waiting for the echo to start and another timeout while waiting for it to finish.
4. Convert pulse width to distance with $d=t\times17{,}150$ cm.
5. Accept only readings between **2 cm and 400 cm**.
6. Keep a rolling median of up to three valid samples.

The left and right sensors are fired sequentially with a **60 ms delay after each reading**, reducing ultrasonic crosstalk. A three-sample median rejects a single outlier:

```text
Raw samples:      [48, 182, 49] cm
Median-filtered:  49 cm
```

This improves stability, but a turn must remain visible across several acquisition passes before the car reacts.

### Wall-Opening Turn Decision

Let $L$ and $R$ be the filtered left and right distances:

$$
\Delta = |L-R|
\qquad
r = \frac{\max(L,R)}{\max(\min(L,R),1)}
$$

A turn candidate is produced when:

$$
\Delta \ge 35\text{ cm}
\quad\text{or}\quad
\left(\Delta \ge 20\text{ cm}\ \land\ r \ge 1.8\right)
$$

If the condition is true, the robot selects the side with the larger measured distance because that side is interpreted as the opening. The two-part rule combines an absolute gap with a proportional comparison:

| Example | $\Delta$ | $r$ | Result |
|---|---:|---:|---|
| $L=48$, $R=51$ cm | 3 cm | 1.06 | Continue straight |
| $L=20$, $R=40$ cm | 20 cm | 2.00 | Right-turn candidate |
| $L=25$, $R=61$ cm | 36 cm | 2.44 | Right-turn candidate |
| $L=60$, $R=24$ cm | 36 cm | 2.50 | Left-turn candidate |

A candidate is accepted only after **three consecutive decisions agree** and the robot has driven forward for at least **1.5 s** since the previous turn. This prevents a single reflection or the previous corner from immediately triggering another maneuver.

### Timed Turn Model

Once a turn is accepted, its exit is based on time rather than a measured heading:

```text
stop → steer → wait → drive for turn_duration → stop → recenter → wait
```

The dashboard's distance display uses the open-loop estimate

$$
v_{\text{est}}=v_{\max}\frac{u}{100},
\qquad
s_{\text{est}}=v_{\text{est}}t
$$

where $u$ is PWM percentage. With the code defaults $v_{\max}=50$ cm/s, turn PWM $u=45\%$, and $t=1.0$ s:

$$
s_{\text{est}}=50\times0.45\times1.0=22.5\text{ cm}
$$

This is a tuning model, not a measured travel distance. Battery voltage, L298N voltage loss, tire slip, floor friction, and motor loading can all change the real turn.

### Steering Calibration

The S3003 servo command is mapped linearly from the calibrated 30°–150° range to a 2.5%–12.5% PWM duty range:

$$
\text{duty}(\%)=2.5+\frac{\theta-30}{120}\times10
$$

| Steering command | Angle | Calculated duty cycle |
|---|---:|---:|
| Left | 81° | 6.75% |
| Center | 106° | 8.83% |
| Right | 131° | 10.92% |

These values are **commanded angles**. The servo has no position sensor, so the program cannot verify the physical wheel angle.

### Calibration Parameters Exposed by the Dashboard

| Parameter | Default | Purpose |
|---|---:|---|
| Forward speed | 55% PWM | Straight-section motor command |
| Turn speed | 45% PWM | Motor command during the timed corner |
| Turn duration | 1.0 s | Determines how long the car drives with steering applied |
| Maximum-speed estimate | 50 cm/s | Converts PWM percentage into dashboard-only speed and distance estimates |
| Manual steering angle | Available only while stopped | Checks linkage travel without driving |

Keeping these values adjustable shortened the test cycle: change one parameter, run the same maneuver, observe telemetry, and compare the result without editing the Python source.

### Failure Handling and Safety

| Condition detected by the code | Response |
|---|---|
| One noisy distance sample | Median filter prevents it from dominating the last three valid samples |
| Echo stuck HIGH, timeout, or value outside 2–400 cm | Reading becomes invalid (`None`) |
| Both ultrasonic readings invalid | No turn is selected |
| Only one ultrasonic reading invalid | Current code treats the invalid side as open and selects that side |
| Browser heartbeat missing for more than 3 s | Finish the active section, stop the motor, and recenter steering |
| Stop or emergency-stop command | Stop motor and return to `stopped` |
| Ctrl+C, SIGINT, or SIGTERM | Stop motor, recenter servo, stop PWM, and release GPIO |

Treating one invalid sensor as open space avoids freezing when a wall gives no echo, but it also creates a clear risk: a disconnected sensor can look like a valid opening. This behavior is documented because it is an important boundary of the uploaded controller.

### Engineering Trade-offs

| Decision | Benefit | Cost |
|---|---|---|
| Sequential ultrasonic firing | Reduces crosstalk | Slower sensing cycle |
| Median of three samples | Rejects isolated spikes | Adds response delay |
| Three matching decisions | Avoids false turns | Opening must remain visible longer |
| 1.5 s post-turn lockout | Prevents immediate retriggering | Cannot accept a new corner during the lockout |
| Stop before steering | Protects the close mechanical layout | Adds 0.9 s stationary time per maneuver |
| Timed turns | Simple and reproducible to tune | Sensitive to speed, voltage, and surface changes |
| Browser heartbeat | Stops the robot if supervision disappears | Safe operation depends on the dashboard connection |
| Open-loop speed estimate | Requires no encoder | Cannot measure true speed, distance, or wheel slip |

The architecture is intentionally simple enough to debug subsystem by subsystem. Its strongest feature is transparency: every autonomous action can be traced to specific sensor values, thresholds, confirmation counts, states, and GPIO commands.

## 🧭 Systems Thinking & Engineering Decisions

Every version of this robot exists because an earlier version failed at something specific. This section is the honest version of that story — what we planned, what actually happened, and why we changed course each time.



### The plan we started with vs. the robot that actually exists

Early in the season we scoped an ambitious electrical architecture. Most of it didn't survive contact with real hardware — and that's a normal part of engineering, not a failure to hide.

| Subsystem | Original plan | What we're actually running | Why it changed |
|---|---|---|---|
| Motor driver | BTS7960 (high-current) | L298N H-bridge | The simpler driver reduced wiring complexity and provides the required PWM speed and direction control |
| Distance sensing | 3× VL53L0X ToF via TCA9548A multiplexer | 1× rear VL53L0X + 2× ultrasonic (left/right) | The multiplexed ToF setup failed to initialize reliably over I²C, *and separately* ToF readings proved unreliable near the mat's black surfaces — two independent reasons pointing the same direction |
| Orientation sensing | MPU6050 IMU | Not present | Removed to reduce integration complexity while stabilizing the core drive loop |
| Power | Protected 3S pack, dual-pack rotation, BMS, two buck converters (5 V logic / 5.5 V servo) | 3S 18500 pack + USB-C power bank (Pi), servo supplied from the H-bridge module's 5 V terminal | Separate motor/Pi sources reduce conducted noise; the unprotected cell pack remains the major electrical risk |

We're not presenting the original plan as a mistake — it was the correct engineering target. What changed is that we chose reliability and debuggability under a real deadline over sophistication we could not fully verify. That trade-off itself is the point of this section.

### Problems encountered — and what we did about each one

**1. ToF sensors were the wrong tool for this mat, twice over.**
Our first plan used three ToF sensors sharing one connection through a multiplexer chip. That setup never worked reliably. Separately, we also found that even a single, correctly-working ToF sensor struggled near the mat's black surfaces — it measures distance by reflecting infrared light, and black absorbs infrared instead of bouncing it back. Two different problems, same answer: we switched to ultrasonic sensors, which use sound instead of light and don't care what color the wall is.

**2. A live wiring mistake, caught before it became a bigger one.**
One ultrasonic sensor was briefly wired backwards (power and ground reversed) and started heating up. We caught it, disconnected it immediately, and rewired it correctly; it has worked since. This is exactly why we treat "every ground wire shares one common rail" as a hard rule everywhere else in this README — it's not caution for caution's sake, it's a lesson from something that actually almost went wrong.

### The pattern across all three

In every case, the fix was to reduce complexity and isolate one failure at a time: fewer sensors on a shared bus instead of debugging a flaky multiplexer, ultrasonic wall sensing instead of relying on infrared reflection, and replacement of the failed IMX219 setup with a working Arducam IMX708 camera.

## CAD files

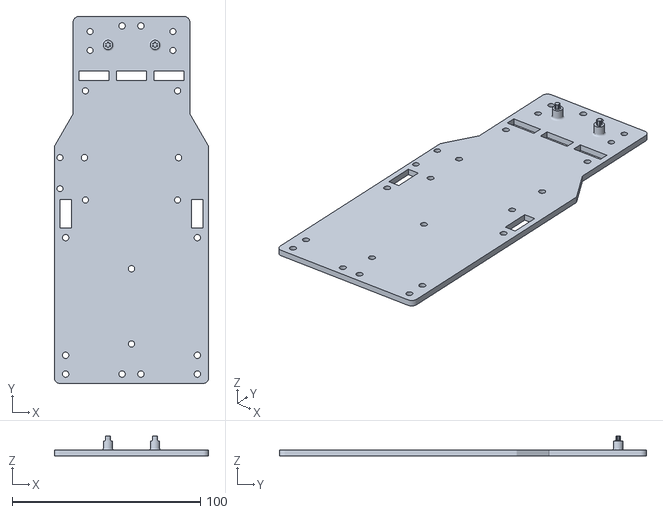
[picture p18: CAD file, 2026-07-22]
models/3D printed stl files/Vehicle_Body_V5.STL
82.0 x 195.0 x 10.5

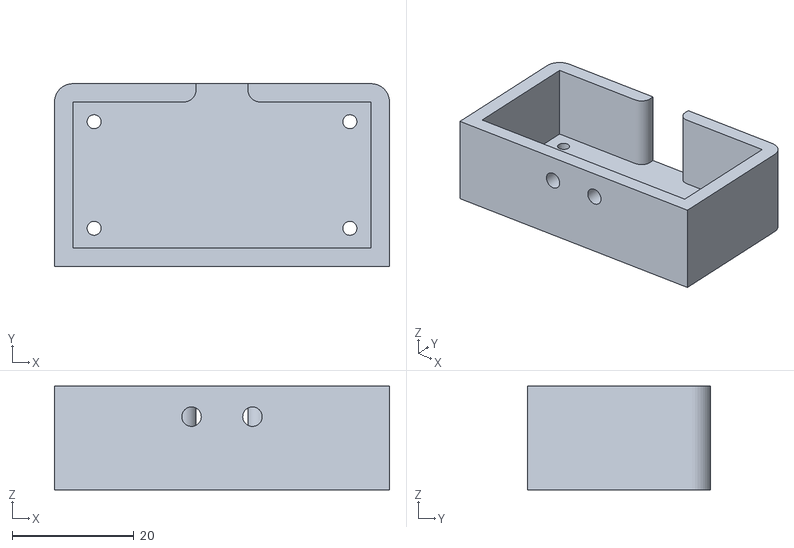
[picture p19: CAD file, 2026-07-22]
models/3D printed stl files/Ultrasonic mount1.STL
55.0 x 30.0 x 17.0

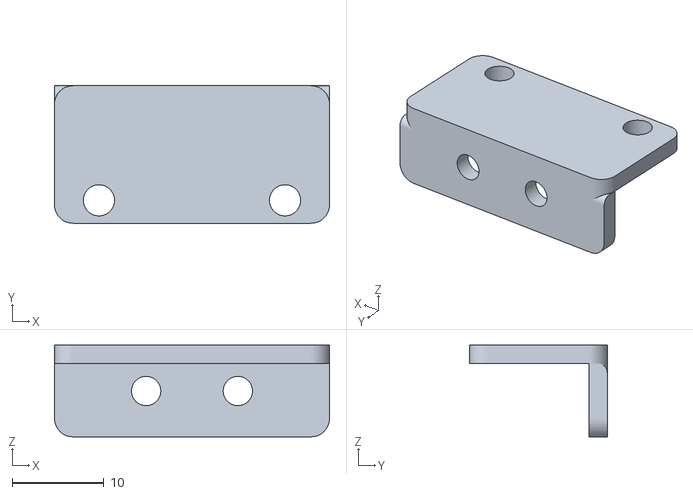
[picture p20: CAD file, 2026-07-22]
models/3D printed stl files/TOF_Mount_V6.STL
30.0 x 15.0 x 10.0

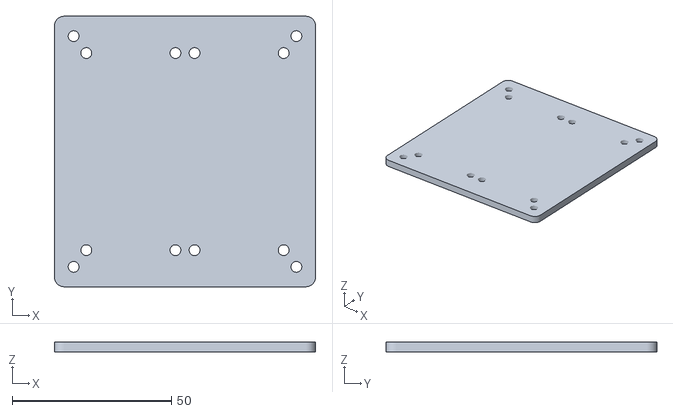
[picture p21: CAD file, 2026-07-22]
models/3D printed stl files/Toppest_layer_V3.STL
82.0 x 85.0 x 3.00

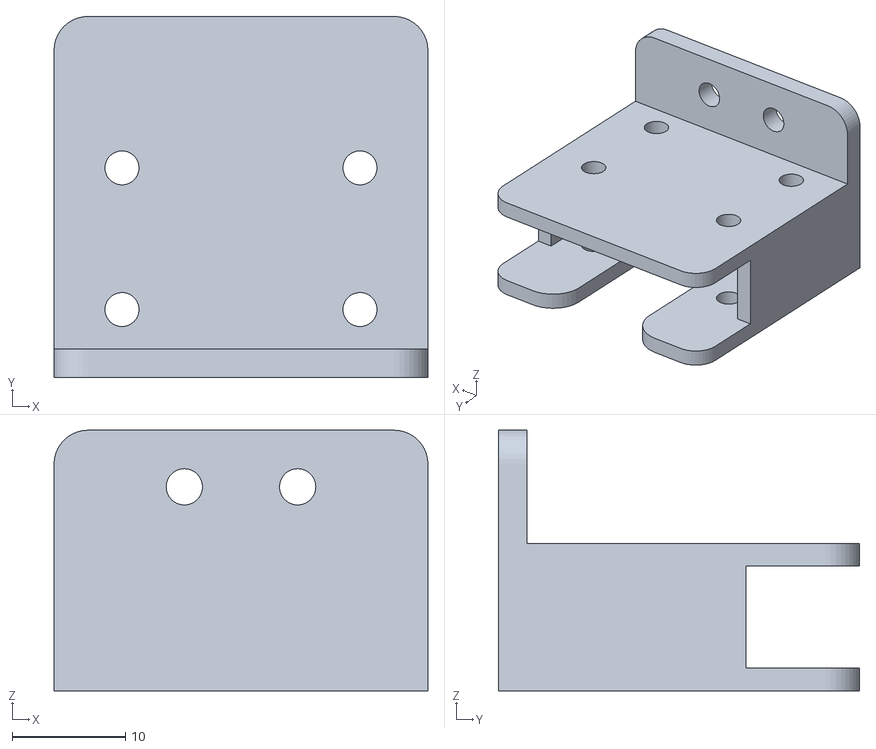
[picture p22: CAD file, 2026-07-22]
models/3D printed stl files/Mount_Camera_tarkeeb_V2.STL
33.0 x 31.9 x 23.0

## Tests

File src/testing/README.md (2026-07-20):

# Source Code

This code was used for testing and calibration of the Open Challenge (Task 1) — sensor readings, servo angles, turn timing, and speed settings were tuned through the live dashboard it exposes. **This is the testing build, not competition code.**



*The dashboard shown in its idle state — sensor readings populate live once connected to the robot.*
## Files

| File | Purpose |
|---|---|
| `dashboard.py` | Main controller. Runs the sensor loop, the drive state machine, and a small HTTP server (port 8080) that serves the dashboard and accepts control commands. |
| `dashboard.html` | Browser dashboard: live sensor readings, start/stop/emergency-stop controls, tunable speed/turn/duration sliders, section-by-section drive history. |

## Hardware this expects

- Raspberry Pi 4 Model B, BCM GPIO numbering
- 1× VL53L0X Time-of-Flight sensor on the default I²C bus, address `0x29` (rear)
- 2× ultrasonic distance sensors (left: TRIG BCM5 / ECHO BCM6, right: TRIG BCM20 / ECHO BCM21)
- 1× 3-wire hobby servo (signal BCM12, 50 Hz) — no position feedback
- 1× H-bridge motor driver (EN/PWM on BCM13, IN1 on BCM23, IN2 on BCM24)

The full pin table, power distribution, electrical checks, and connection reasoning are documented in the root README under [Power & Sensor Architecture](../../README.md#power--sensor-architecture).

## Dependencies

```bash
pip install adafruit-circuitpython-vl53l0x adafruit-blinka RPi.GPIO
```

## Running it

1. Place `dashboard.py` and `dashboard.html` in the **same folder** on the Pi, as `/home/sunbird/dashboard.py` and `/home/sunbird/dashboard.html` — the path is hardcoded in `dashboard.py` (`HTML_PATH`), so the HTML file must sit at exactly that path or you'll need to edit that constant.
2. SSH into the Pi and run:
   ```bash
   python3 dashboard.py
   ```
3. Open `http://raspberrypi.local:8080` (or the Pi's IP) in a browser on the same network.
4. **Raise the drive wheels off the ground before the first Start** — see the safety checklist in the root README.

## Safety behavior already built in

- If the browser stops sending its once-per-second heartbeat for more than 3 seconds, the robot force-stops and recenters the steering automatically.
- The motor is always commanded to stop before any steering change.
- `Ctrl+C` / `SIGTERM` triggers a clean shutdown: stop motor, recenter servo, stop PWM, release GPIO.

## Known limitations (intentional, documented in code)

- Speed and distance are **open-loop estimates** (`estimated_speed = max_speed_cm_s × pwm% / 100`, integrated over time) — there is no wheel encoder, so these numbers are not ground truth.
- The servo has no position feedback; the dashboard shows the *commanded* angle only.

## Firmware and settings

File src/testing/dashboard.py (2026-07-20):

#!/usr/bin/env python3
"""Sunbird robot dashboard and timed autonomous drive controller."""

import copy
import json
import signal
import statistics
import threading
import time
from collections import deque
from http.server import BaseHTTPRequestHandler, ThreadingHTTPServer
from urllib.parse import parse_qs, urlparse

import adafruit_vl53l0x
import board
import RPi.GPIO as GPIO


# BCM GPIO numbering (physical pin numbers are in the comments).
LEFT_TRIG = 5       # physical pin 29
LEFT_ECHO = 6       # physical pin 31
RIGHT_TRIG = 20     # physical pin 38
RIGHT_ECHO = 21     # physical pin 40
SERVO_PIN = 12      # physical pin 32
MOTOR_EN = 13       # physical pin 33
MOTOR_IN1 = 23      # physical pin 16
MOTOR_IN2 = 24      # physical pin 18

# Steering calibration. Swap LEFT_ANGLE and RIGHT_ANGLE if steering is reversed.
SERVO_MIN_ANGLE = 30
SERVO_MAX_ANGLE = 150
CENTER_ANGLE = 106
LEFT_ANGLE = 81
RIGHT_ANGLE = 131

# Sensor and autonomous-control tuning.
ULTRA_MAX_CM = 400.0
AUTO_DIFF_CM = 35.0
AUTO_RATIO = 1.8
DECISION_CONFIRMATIONS = 3
MIN_SECTION_TIME_S = 1.5
SERVO_SETTLE_S = 0.45
WATCHDOG_S = 3.0

# PWM calibration.
SERVO_MIN_DUTY = 2.5
SERVO_MAX_DUTY = 12.5
MOTOR_PWM_HZ = 1000

HTML_PATH = "/home/sunbird/dashboard.html"


GPIO.setwarnings(False)
GPIO.setmode(GPIO.BCM)
GPIO.setup(LEFT_TRIG, GPIO.OUT, initial=GPIO.LOW)
GPIO.setup(RIGHT_TRIG, GPIO.OUT, initial=GPIO.LOW)
GPIO.setup(LEFT_ECHO, GPIO.IN)
GPIO.setup(RIGHT_ECHO, GPIO.IN)
GPIO.setup(SERVO_PIN, GPIO.OUT, initial=GPIO.LOW)
GPIO.setup(MOTOR_EN, GPIO.OUT, initial=GPIO.LOW)
GPIO.setup(MOTOR_IN1, GPIO.OUT, initial=GPIO.LOW)
GPIO.setup(MOTOR_IN2, GPIO.OUT, initial=GPIO.LOW)

servo_pwm = GPIO.PWM(SERVO_PIN, 50)
motor_pwm = GPIO.PWM(MOTOR_EN, MOTOR_PWM_HZ)
servo_pwm.start(0)
motor_pwm.start(0)

state_lock = threading.RLock()
servo_lock = threading.Lock()
motor_lock = threading.Lock()
state = {
    "tof_mm": None,
    "left_cm": None,
    "right_cm": None,
    "sensor_time": 0.0,
    "sensor_seq": 0,
    "angle": CENTER_ANGLE,
    "steering_direction": "center",
    "steering_reason": "Robot stopped",
    "running": False,
    "run_requested": False,
    "drive_state": "stopped",
    "motor_pwm": 0,
    "forward_speed": 55,
    "turn_speed": 45,
    "turn_duration": 1.0,
    "max_speed_cm_s": 50.0,
    "estimated_speed_cm_s": 0.0,
    "section_number": 0,
    "section_distance_cm": 0.0,
    "section_time_s": 0.0,
    "sections": [],
    "status_message": "Press Start Robot when the area is safe",
    "last_heartbeat": time.monotonic(),
}


def clamp(value, low, high):
    return max(low, min(high, value))


def angle_to_duty(angle):
    span = SERVO_MAX_ANGLE - SERVO_MIN_ANGLE
    position = (angle - SERVO_MIN_ANGLE) / span
    return SERVO_MIN_DUTY + position * (SERVO_MAX_DUTY - SERVO_MIN_DUTY)


def set_servo_angle(angle):
    """Set the commanded angle; a three-wire servo has no position feedback."""
    angle = int(round(clamp(float(angle), SERVO_MIN_ANGLE, SERVO_MAX_ANGLE)))
    with servo_lock:
        servo_pwm.ChangeDutyCycle(angle_to_duty(angle))
    with state_lock:
        state["angle"] = angle
    return angle


def motor_forward(duty):
    duty = round(clamp(float(duty), 0.0, 100.0), 1)
    with motor_lock:
        GPIO.output(MOTOR_IN1, GPIO.HIGH)
        GPIO.output(MOTOR_IN2, GPIO.LOW)
        motor_pwm.ChangeDutyCycle(duty)
    with state_lock:
        state["motor_pwm"] = duty


def motor_stop():
    with motor_lock:
        motor_pwm.ChangeDutyCycle(0)
        GPIO.output(MOTOR_IN1, GPIO.LOW)
        GPIO.output(MOTOR_IN2, GPIO.LOW)
    with state_lock:
        state["motor_pwm"] = 0
        state["estimated_speed_cm_s"] = 0.0


def estimated_speed(pwm_percent, max_speed_cm_s):
    """Open-loop estimate only; actual speed requires a wheel encoder."""
    return max_speed_cm_s * clamp(pwm_percent, 0.0, 100.0) / 100.0


motor_stop()
set_servo_angle(CENTER_ANGLE)


def init_tof():
    try:
        i2c = board.I2C()
        sensor = adafruit_vl53l0x.VL53L0X(i2c)
        print("ToF sensor initialized at 0x29")
        return sensor
    except Exception as exc:
        print(f"ToF initialization failed: {exc}")
        return None


tof_sensor = init_tof()
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

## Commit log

2026-04-14 Add sensor selection analysis — distance sensors
2026-07-19 Chassis_edit 2
2026-07-19 Steering_caliberation readme
2026-07-20 Add current testing/calibration code
2026-07-20 Create README.md for testing and calibration
    Added README.md for testing and calibration of the Open Challenge, detailing files, hardware requirements, dependencies, running instructions, safety behaviors, and known limitations.
2026-07-20 Revise sensor and camera troubleshooting sections
    Updated the README to reflect changes in sensor usage and camera investigation details.
2026-07-20 Update power configuration details in README
2026-07-20 Document power and sensor architecture
2026-07-20 Update power sources table in README
    Removed pending voltage and runtime note for the 3S motor pack.
2026-07-20 Revise sensor description and timing control details
    Updated explanation of sensor functionality and measurement cycle.
2026-07-21 Add animated Ackermann steering visual
2026-07-21 Embed animated Ackermann steering visual
2026-07-21 docs: add camera vision pipeline visual
2026-07-21 docs: add camera ROI selection visual
2026-07-22 circuit diagram
2026-07-22 3d printed files
    [Mount_Camera_tarkeeb_V2.STL, TOF_Mount_V6.STL, Toppest_layer_V3.STL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]
